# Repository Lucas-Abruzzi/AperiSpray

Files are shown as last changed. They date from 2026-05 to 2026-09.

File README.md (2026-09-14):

# AperiSpray

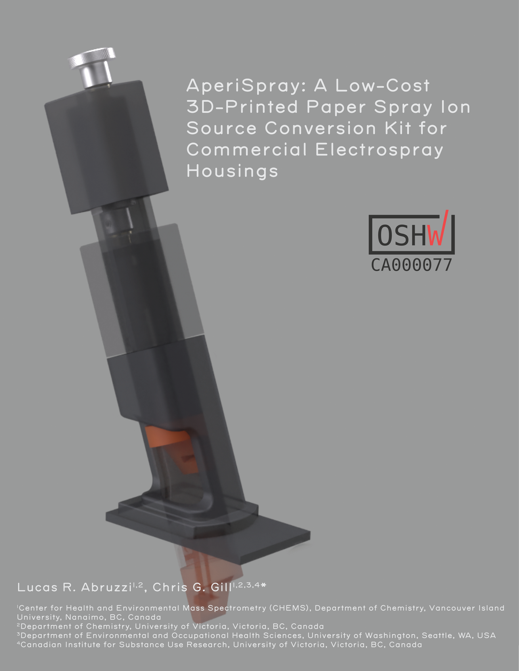
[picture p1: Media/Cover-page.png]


## Table of Contents
- [Overview of Source](https://github.com/Lucas-Abruzzi/AperiSpray/tree/main#overview-of-source)
    - [Disclaimer](https://github.com/Lucas-Abruzzi/AperiSpray/tree/main#disclaimer)
    - [Schematic](https://github.com/Lucas-Abruzzi/AperiSpray/tree/main#schematic)
    - [Parts List](https://github.com/Lucas-Abruzzi/AperiSpray/tree/main#parts-list)
- [Source Construction](https://github.com/Lucas-Abruzzi/AperiSpray/tree/main#source-construction)
    - [3D Printing](https://github.com/Lucas-Abruzzi/AperiSpray/tree/main#printing-parts)
    - [Source Disassembly](https://github.com/Lucas-Abruzzi/AperiSpray/tree/main#source-disassembly)
    - [Soldering the Electronics](https://github.com/Lucas-Abruzzi/AperiSpray/tree/main#soldering-electronics)
    - [Assembling the Shaft Assembly](https://github.com/Lucas-Abruzzi/AperiSpray/tree/main#assembling-the-shaft-assembly)
    - [Assembling the High-Voltage Termination](https://github.com/Lucas-Abruzzi/AperiSpray/tree/main#assembling-the-high-voltage-termination)
    - [Installing the Strip Mount](https://github.com/Lucas-Abruzzi/AperiSpray/tree/main#installing-the-strip-mount)
    - [Installing Assembly in the ESI Housing](https://github.com/Lucas-Abruzzi/AperiSpray/tree/main#installing-assembly-in-the-esi-housing)
- [Opensource Strip Cartridge Construction](https://github.com/Lucas-Abruzzi/AperiSpray/tree/main#opensource-strip-cartridge-construction)
    - [Cutting Paper Strips](https://github.com/Lucas-Abruzzi/AperiSpray/tree/main#cutting-paper-strips)
    - [Printing Strip Holder and Strip Holder Clips](https://github.com/Lucas-Abruzzi/AperiSpray/tree/main#printing-strip-holders-and-strip-holder-clips)
    - [Assembling Strip Cartridges](https://github.com/Lucas-Abruzzi/AperiSpray/tree/main#assembling-strip-cartridges)
- [Operating Instructions](https://github.com/Lucas-Abruzzi/AperiSpray/tree/main#operating-instructions)
    - [Positioning Calibration Procedure](https://github.com/Lucas-Abruzzi/AperiSpray/tree/main#positioning-calibration-procedure)
    - [Spray Solvent Delivery Set Up](https://github.com/Lucas-Abruzzi/AperiSpray/tree/main#spray-solvent-delivery-set-up)
    - [Method Development](https://github.com/Lucas-Abruzzi/AperiSpray/tree/main#method-development)
    - [Sample Preparation](https://github.com/Lucas-Abruzzi/AperiSpray/tree/main#sample-preparation)
    - [Loading and Analyzing a Strip Cartridge](https://github.com/Lucas-Abruzzi/AperiSpray/tree/main#loading-and-analyzing-a-strip-cartridge)
    - [Trouble Shooting](https://github.com/Lucas-Abruzzi/AperiSpray/tree/main#trouble-shooting)
    - [Unloading Used Strip Cartridges](https://github.com/Lucas-Abruzzi/AperiSpray/tree/main#unloading-used-strip-cartridges)

## Overview of Source

The AperiSpray is a low-cost, simple to use assembly that converts existing Thermo Scientific OptaMax NG heated electrospray ionization (H-ESI) housings into paper spray ion sources, making use of 3D-printed parts and off-the-shelf hardware. AperiSpray features instrument-controlled high-voltage and spray solvent delivery and can use either in-house-built or commercially available paper spray strips. Many laboratories that perform routine LC-MS analyses already have surplus H-ESI sources available for conversion, and those that don’t, can purchase inexpensive used or defective housings from third party sellers, making AperiSpray a low-investment option for those wanting to experiment with PS-MS. Additionally, unlike the commercial PS-MS platform, AperiSpray is compatible with almost any Thermo Scientific mass spectrometer with an atmospheric pressure interface, allowing it to be coupled to high-resolution Orbitrap instruments. Although outside the scope of this document, components of this design could be adapted to construct PSI sources for instruments from other manufacturers.

### Disclaimer

Following these instructions may void instrument warranties, risk damage to instruments, and/or expose you to risk of electrical shock. Do so at your own risk. Do not perform modifications to the source while it is mounted to the instrument. Ensure that the instrument is in “standby” or “off” before attempting to load or unload a strip cartridge from the source and never raise the shaft while the spray voltage is turned on.

### Schematic

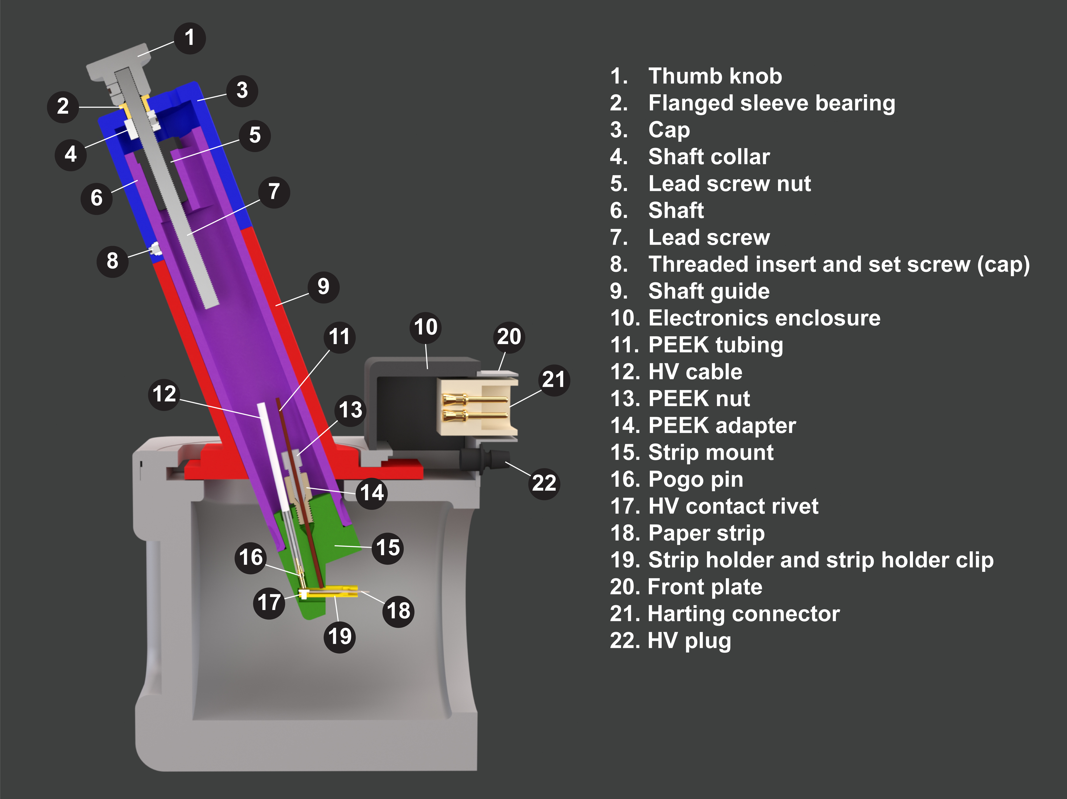
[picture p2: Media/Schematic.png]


### Parts List

| Designator | Qty | Source | Part No. | Cost /ea (CAD) | Material |
| --- | --- | --- | --- | --- | --- |
| Shaft guide  | 1 | 3D-printed | N/A | $2.43 | PLA-CF |
| Shaft  | 1 | 3D-printed | N/A | $2.46 | PLA-CF |
| Cap  | 1 | 3D-printed | N/A | $1.46 | PLA-CF |
| Electronics enclosure | 1 | 3D-printed | N/A | $1.60 | PLA-CF |
| HV female connector | 1 | 3D-printed | N/A | $0.16 | PLA |
| Strip mount | 1 | 3D-printed | N/A | $0.72 | PA6-GF |
| Strip holder + clip  | N/A* | 3D-printed | N/A | $0.06 | PA6-GF |
| Strip tray | 1 | 3D-printed | N/A | $0.73 | PLA |
| Harting connector | 1 | Digikey.ca | [1195-1808-ND](https://www.digikey.ca/en/products/detail/harting/09200102612/3180391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) | $29.82 | PC |
| 2.15 kΩ resistor | 1 | Digikey.ca | [56-SFR2500002151FR500CT-ND](https://www.digikey.ca/en/products/detail/vishay-beyschlag-draloric-bc-components/SFR2500002151FR500/595788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) | $0.20 | Ceramic |
| 22 MΩ resistor | 1 | Digikey.ca | [BC4913CT-ND](https://www.digikey.ca/en/products/detail/vishay-beyschlag-draloric-bc-components/VR37000002205JA100/7350819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) | $0.74 | Ceramic |
| Pogo pin | 1 | Digikey.ca | [54-7949-0-15-20-09-14-11-0-ND](https://www.digikey.ca/en/products/detail/mill-max-manufacturing-corp/7949-0-15-20-09-14-11-0/13531603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) | $4.76 | Brass alloy |
| 20 AWG wire | 4 cm | mcmaster.com | [8054T184](https://www.mcmaster.com/products/8054t184/) | $0.02 | Copper |
| HV cable | 70 cm | mcmaster.com | [8296K17](https://www.mcmaster.com/products/8296k17/) | $25.67 | Silicone |
| 1/4"-PP tubing | 6 cm | mcmaster.com | [5392K12](https://www.mcmaster.com/catalog/132/170/5392K12) | $0.20 | PP |
| Threaded insert | 1 | mcmaster.com | [94100A110](https://www.mcmaster.com/products/94100a110/) | $0.70 | SS |
| Set screw (cap) | 1 | mcmaster.com | [92605A098](https://www.mcmaster.com/products/92605a098/) | $0.15 | SS |
| Thumb knob | 1 | mcmaster.com | [2577K21](https://www.mcmaster.com/products/2577k21/) | $12.57 | SS |
| Flanged sleeve bearing | 1 | mcmaster.com | [7815K11](https://www.mcmaster.com/products/7815k11/) | $5.17 | Bronze |
| Lead screw | 1 | mcmaster.com | [6350K694](https://www.mcmaster.com/products/6350k694/) | $81.44 | SS |
| Shaft collar | 1 | mcmaster.com | [6462K12](https://www.mcmaster.com/products/6462k12/) | $7.17 | SS |
| Lead screw nut | 1 | mcmaster.com | [6350K683](https://www.mcmaster.com/products/6350k683/) | $31.63 | POM |
| Mounting screws | 2 | mcmaster.com | [92196A151](https://www.mcmaster.com/products/92196a151/) | $0.11 | SS |
| Set screw (strip-mount) | 1 | mcmaster.com | [92765A005](https://www.mcmaster.com/products/92765a005/) | $0.33 | Steel alloy |
| HV contact rivets | N/A* | aliexpress.com | [GB109](https://www.aliexpress.com/item/1005007409269038.html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) | $0.03 | Aluminum |
| Chromatography paper | N/A* | Fishersci.ca | [057146](https://www.fishersci.ca/shop/products/whatman-31et-chr-chromatography-paper/057146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) | $0.02 | Cellulose |
| PEEK nut | 1 | Coleparmer.ca | [0201343](https://www.coleparmer.ca/i/idex-fingertight-one-piece-long-thread-natural-peek-1-16-od-tubing-10-32-coned-10-pk/0201343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) | $11.32 | PEEK |
| PEEK nut adapter | 1 | Coleparmer.ca | [0201420](https://www.coleparmer.ca/i/idex-threaded-adapter-peek-0-040-id-10-32-coned-f-to-1-4-28-flat-bottom-m/0201420) | $40.81 | PEEK |
| Crimp butt connector | 1 | grainger.ca | [GGE4FRH9](https://www.grainger.ca/en/product/SPLICE-CONNECTOR-VINYL-RED-PK100/p/GGE4FRH9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) | $0.13 | Vinyl |
| Pen tube | 1 | grainger.ca | [TOYGSM11-2](https://www.grainger.ca/en/product/PEN-BALLPT-MED-BIC-ROUND-BLUE-12-PK/p/TOYGSM11-2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) | $0.47 | PP |
| Heat shrink | 1 | homedepot.ca | [1000843481](https://www.homedepot.ca/product/gardner-bender-3-inch-l-x-assorted-diameter-heat-shrink-black-tubing-set-of-160-/1000843481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) | $25.41 | Polyolefin |

*Denotes consumable

## Source Construction

### Printing Parts

#### Filament
For the cap, shaft, shaft guide, electronics enclosure, and strip tray, most standard FDM filament materials are acceptable. We prefer carbon-fiber PLA because it is dimensionally stable, easy to print and has a desirable surface texture. For the strip mount and strip holders, we recommend a material that is resistant to solvent to prevent interference and instrument contamination. In normal operation of the source, the strip mount should not come in direct contact with spray solvent, so PLA or ABS can be used if necessary, however in our experience, solvent overflow will occasionally occur while calibrating solvent deposition rate and volume, so a solvent-resistant material is highly recommended. Strip holders come in contact with solvent during normal operation. Some good options for strip holders (and strip mounts) include natural polyoxymethylene (POM), and natural PA6 Nylon. We recommend natural glass fiber reinforced PA6 nylon as it is both chemically resistant and easy to print on consumer grade printers, whereas POM suffers from poor print-bed adhesion and severe warping.

#### Printer Settings
Printer settings are highly dependent on the filament material and printer. We recommend using your printer’s default print settings for the filament chosen and adjusting as necessary.

#### Slicer Settings

<ins>Shaft guide:</ins>

Print the shaft guide in an upright position. Tree support is recommended for the overhang in the loading cutaway.

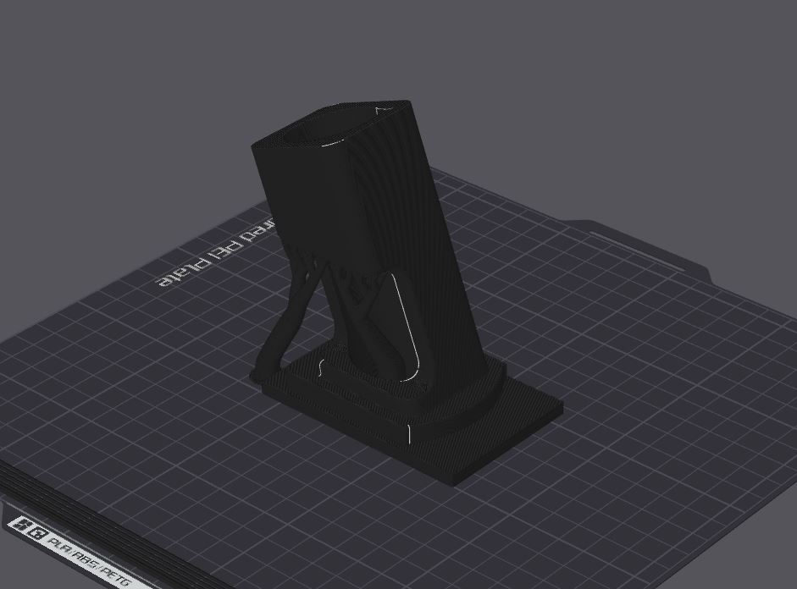
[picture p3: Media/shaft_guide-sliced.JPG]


<ins>Shaft:</ins>

We recommend printing the shaft upright to ensure the surface that mates with the lead screw nut is flat. You will need support under the mounting bracket on the inside of the shaft. 

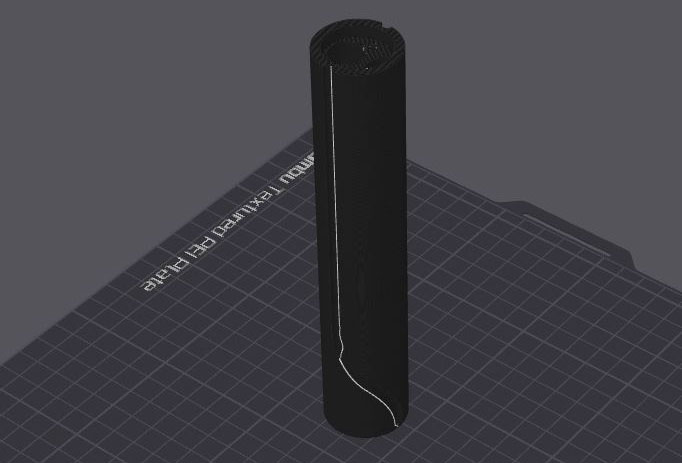
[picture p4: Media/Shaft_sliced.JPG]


<ins>Cap:</ins>

The cap should be printed upside down with the top face against the build plate. No support is necessary. We recommend using a contrasting filament for the warning text and HV symbol if multi-filament printing is available. 

<ins>Electronics enclosure:</ins>

Print the electronics enclosure with the backside down on the build plate. Support is only needed for the bottom lips.

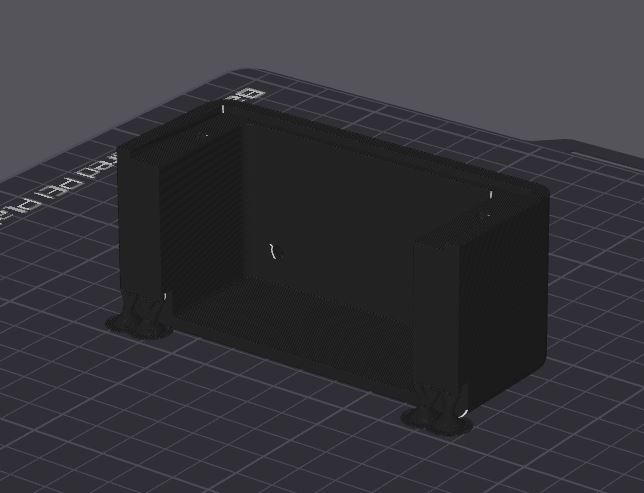
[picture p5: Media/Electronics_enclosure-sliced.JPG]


<ins>HV female connector:</ins>

Print with the threaded end up. No support is needed.

<ins>Strip mount (for open-source or commercial strips):</ins>

The strip mount is best printed upside down with support under the ridge, in the strip pocket, and in the threaded solvent hole.

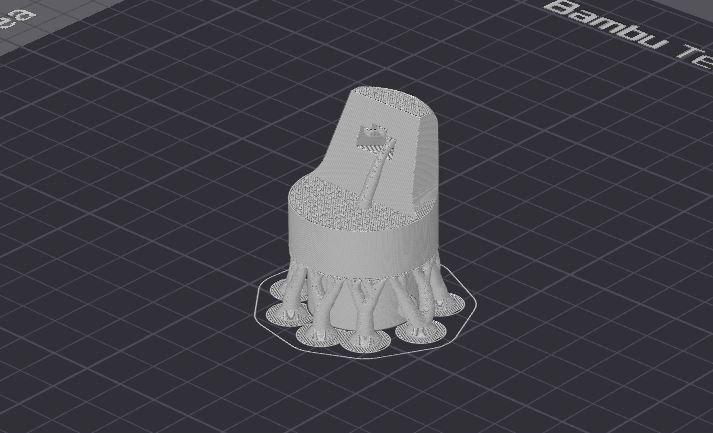
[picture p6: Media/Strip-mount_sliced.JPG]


<ins>Calibration Strips:</ins>

Calibration strips are for calibrating the paper strip position relative to the inlet of the mass spectrometer. They are inserted into the strip pocket on the strip mount and extend to where the opening of the inlet should be relative to the strip mount. By default, the calibration strips extend 4 mm further from the strip mount than actual paper strips would to create a 4 mm gap between paper strips and the inlet when used to calibrate positioning. If a larger or smaller gap is desired, the FreeCAD file for the calibration strips can be modified by increasing or decreasing the “Inlet_gap” variable in the variable set. Print calibration strips out of whatever filament you have on hand. They are best printed in an upright position with the backside against the print bed. Support is only necessary on the calibration strip for the commercial strip mount.

### Source Disassembly

Remove the 4 screws holding the front plate on the source and pull the front plate away from the housing.



Remove the metal cover protecting the electronic and pneumatic connections.

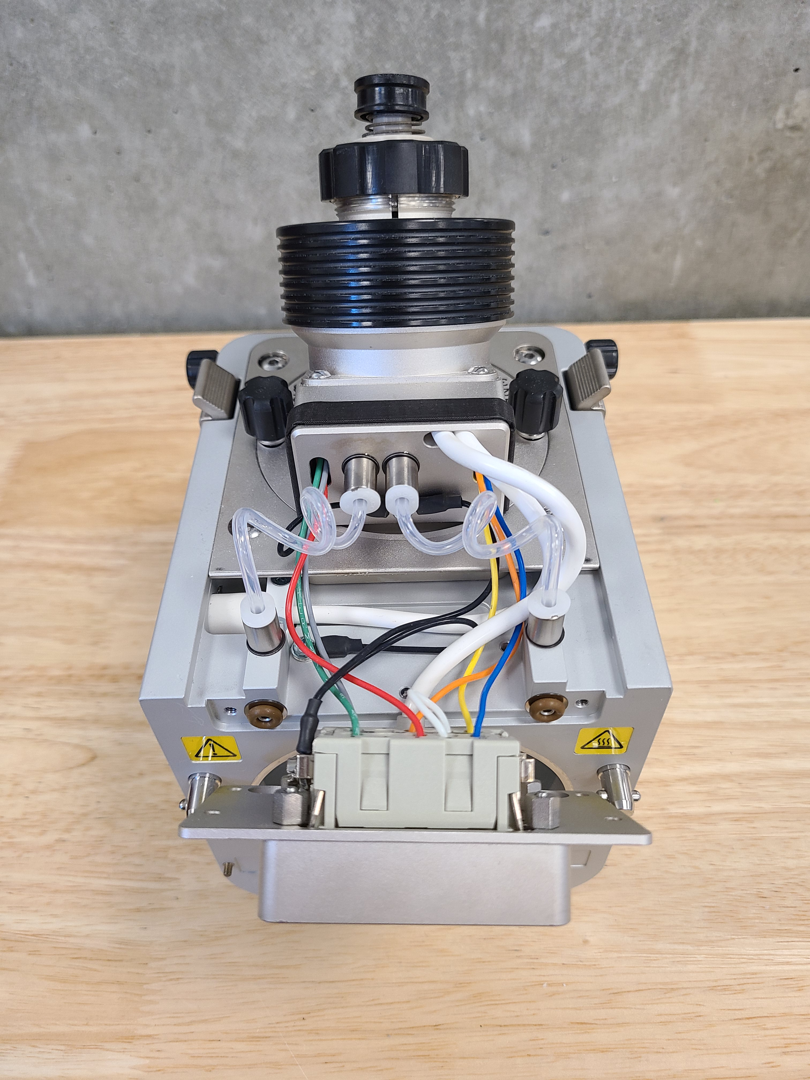
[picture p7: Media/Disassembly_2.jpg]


Disconnect gas lines by pushing down on quick connect tab while pulling up on gas tubing. Remove the retainer knobs for the API spray insert and heater assembly and the 4 socket head screws that mount the spray insert and heater assembly to the housing. 

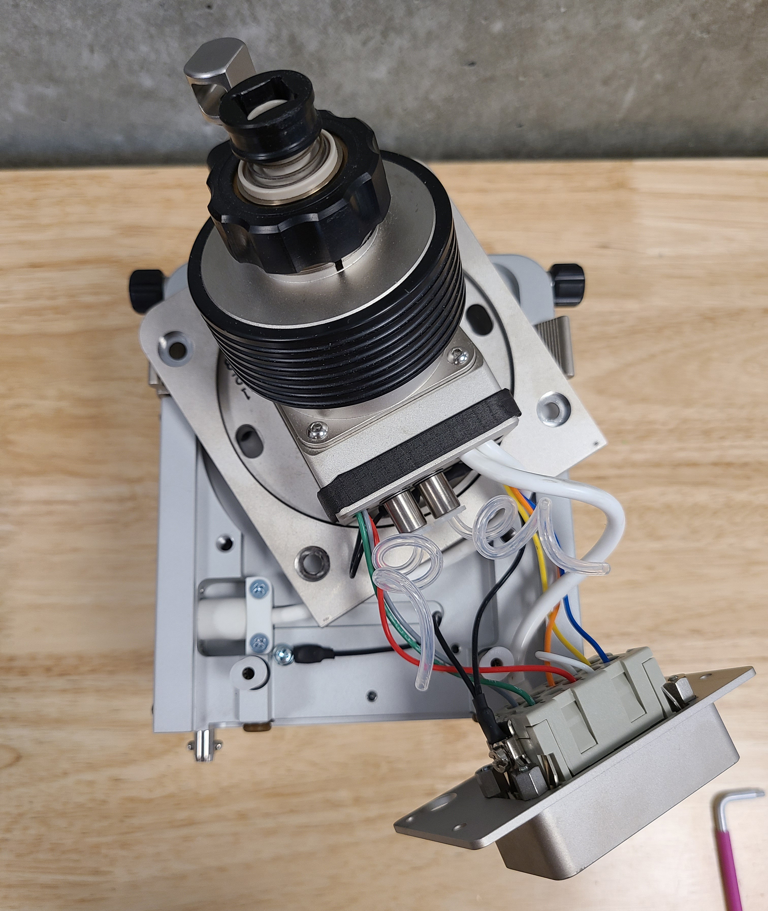
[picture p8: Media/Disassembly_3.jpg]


Remove the 3 socket head screws and the side panel on the right side of the housing. 



Remove the 4 socket head screws and metal plate covering the APCI corona discharge needle high-voltage connection.



Remove the 2 screws and the plastic mount housing the high-voltage corona discharge needle connector and adjacent grounding connection. The right-side panel can be replaced.



Remove the API spray insert and the 4 socket head screws and the heater assembly cover.

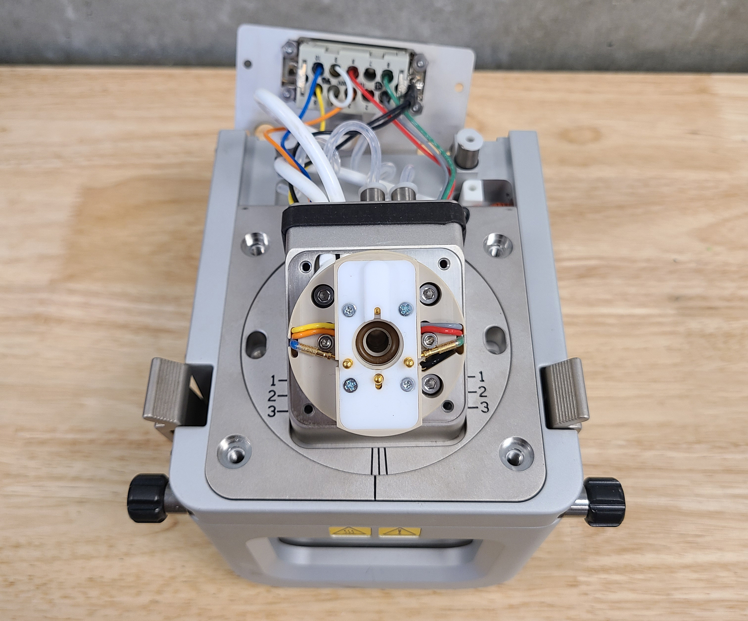
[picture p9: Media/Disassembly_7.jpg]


Remove 3 socket head screws holding on the heater assembly and carefully pull the heater assembly away from the mounting body while feeding wire.

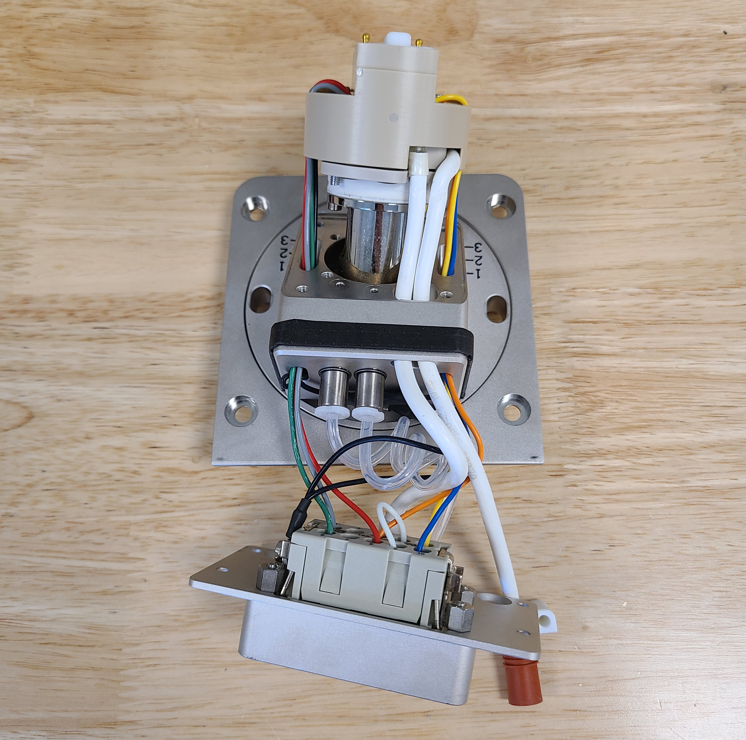
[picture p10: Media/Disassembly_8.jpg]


Carefully slide the positioning plates up and over the heater assembly and electrical connections to separate them from the electronic components

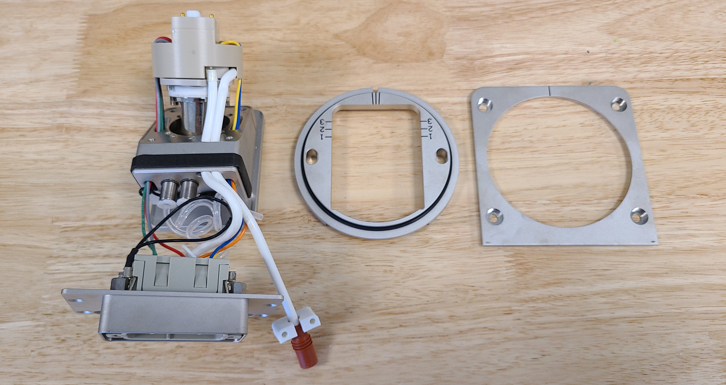
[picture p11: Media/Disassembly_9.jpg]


Loosen and remove the 4 nuts retaining the 10-pin Harting connector to the front plate and unscrew the transparent square nut connecting the HV wire to the HV plug on the front plate.

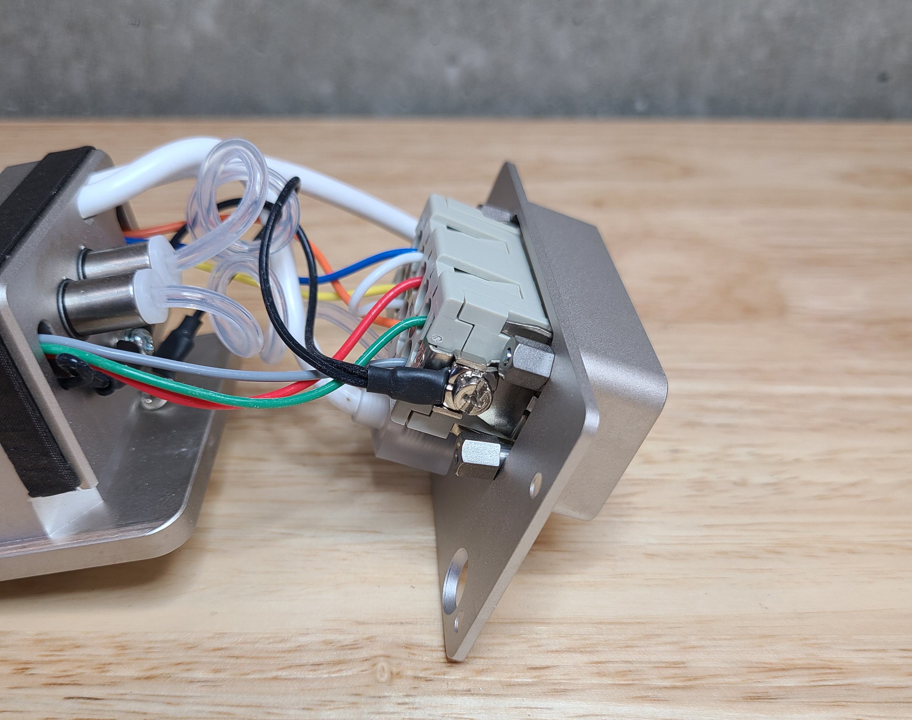
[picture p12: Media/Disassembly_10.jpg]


Separate the connector from the front plate.

### Soldering the Electronics

Add the nuts from the original Harting connector to the new one and mount the new connector to the front plate. Thread a 3/8-32 panel nut onto the HV plug to clamp it to the front plate and tighten it to prevent the HV plug from turning freely in the front plate. 

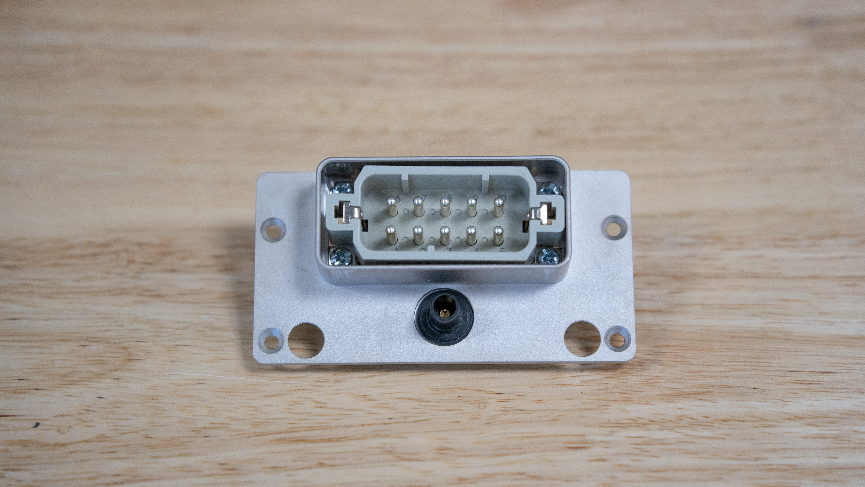
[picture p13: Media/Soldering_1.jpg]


Cut a 10 cm section of HV wire and strip 1 cm from each end. Cut a second 60 cm section and strip 1 cm from one end. Solder the 22 MOhm resistor between the two sections of HV wire. Cut a 6 cm section of 1/4”- polypropylene tubing and slide it over the resistor. 

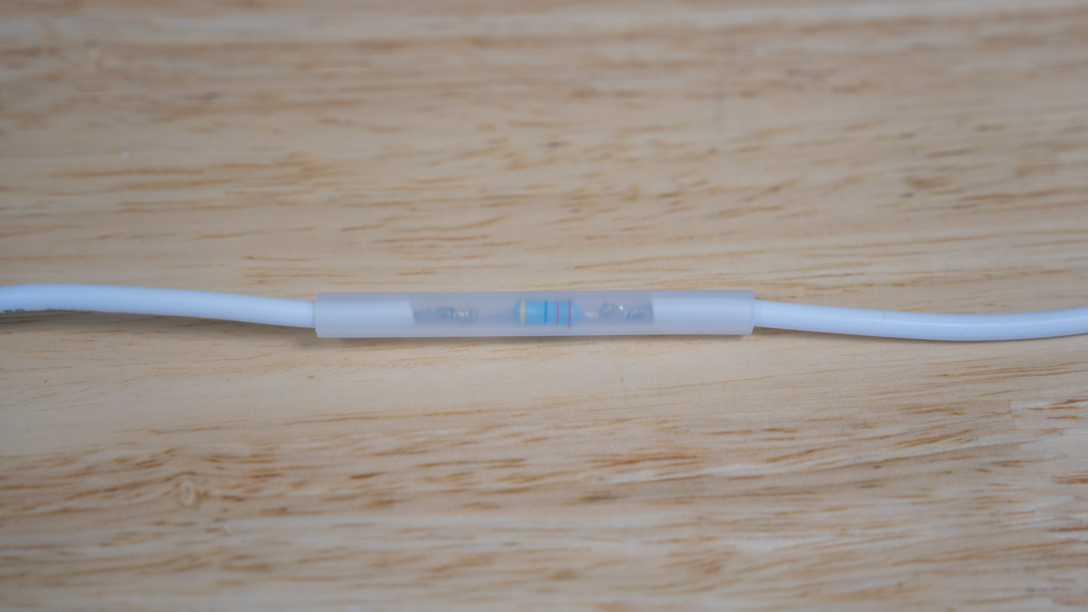
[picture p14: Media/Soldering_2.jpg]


Add heat shrink over the tubing. Add a short section of heat shrink to each end of the previous heat shrink to prevent the tube from sliding. Feed the long end of the HV cable through the port in the top of the 3D-printed electronics enclosure and carefully fold the resistor in.

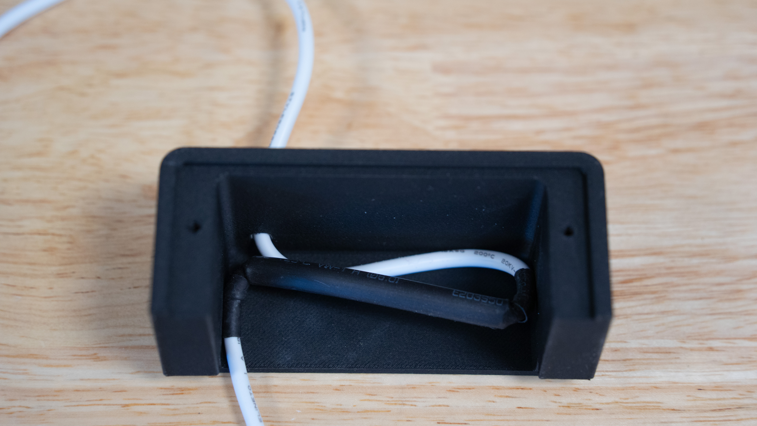
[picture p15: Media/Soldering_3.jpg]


Cut the plastic insulation off one end of a butt splice crimp connector using wire cutters.



Slide the 3D-printed HV connector onto the short end of the HV wire with the threaded end facing out. Feed the short end of the HV wire into the uncut end of the crimp connector and crimp. Slide the cut end of the crimp connector over the gold-plated solder well on the inside end of the HV plug mounted to the front plate. It should slide on easily but make firm contact.

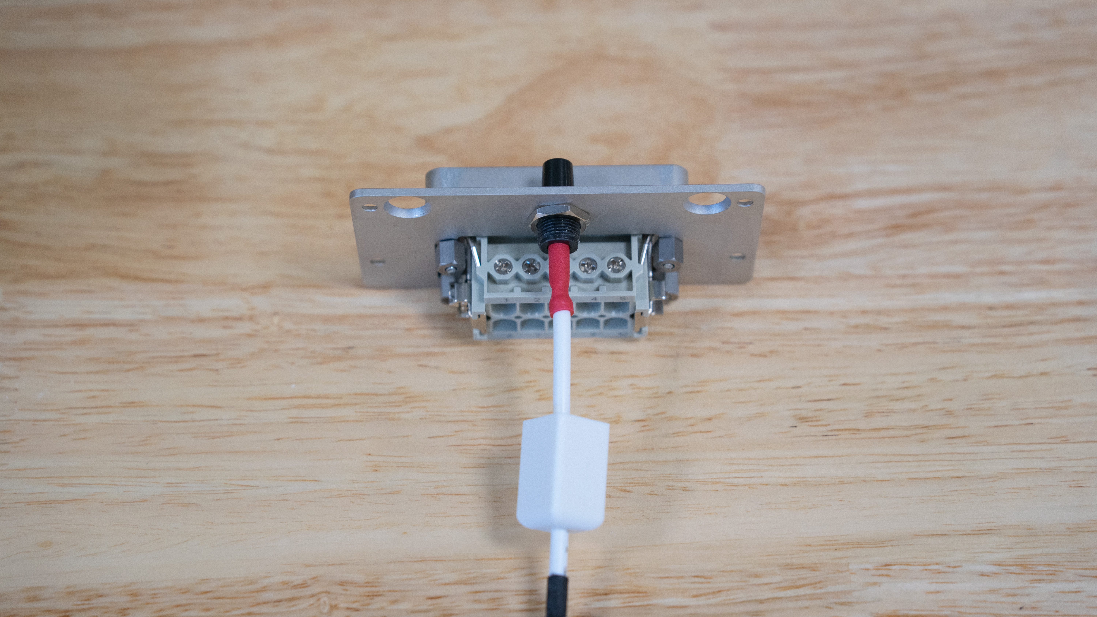
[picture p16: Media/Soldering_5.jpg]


Heat shrink a 2.15 kOhm resistor, leaving the last 5 mm of each lead exposed. Strip 5 mm from each end of a 4 cm section of wire to make a jumper. Place the resistor between pins 6 and 10 in the Harting connector and place the wire jumper between pins 4 and 9. Tighten the set screws fix the connections.

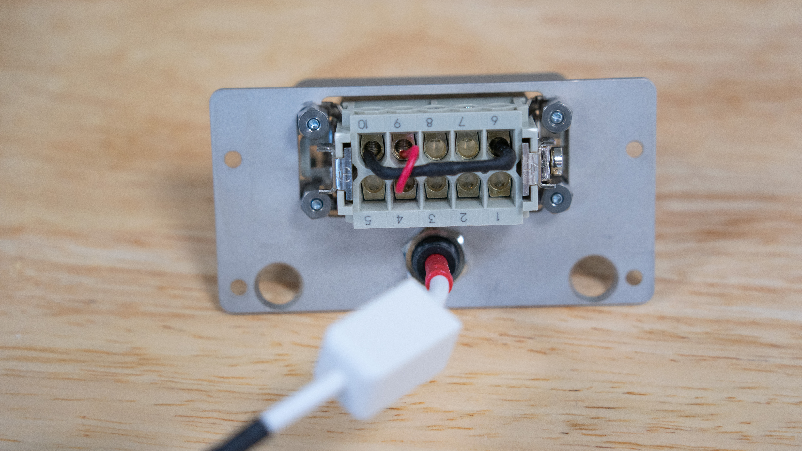
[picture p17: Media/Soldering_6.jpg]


Thread the 3D-printed HV female connector onto the inside end of the HV plug and tighten to secure the crimped HV line to the HV plug. Carefully fold the HV cable into the 3D-printed electronics enclosure and mount the front plate to the electronics enclosure using the 2 of the original flush head mounting screws.

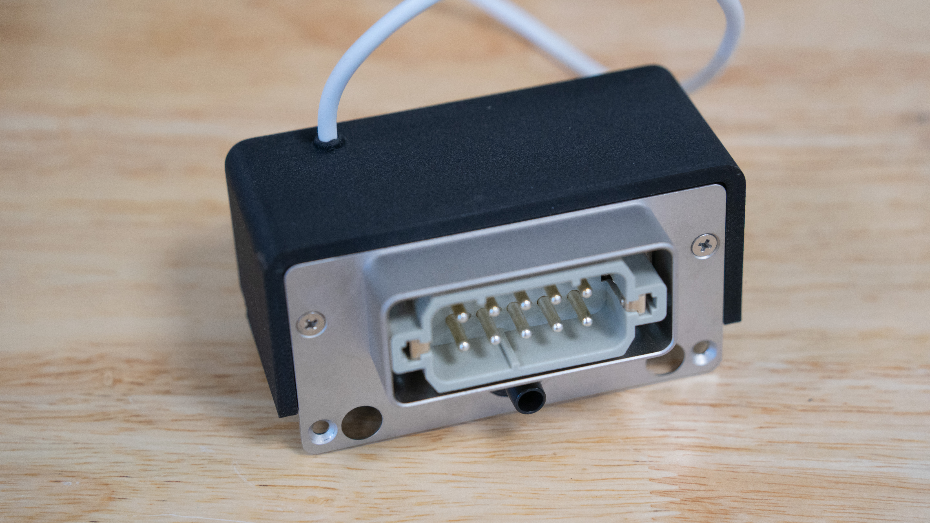
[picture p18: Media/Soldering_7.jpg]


### Assembling the Shaft Assembly

Cut the 1/4-40 lead screw to a length of approximately 9 cm using whatever cutting tool you have on hand. The threads on the cut end do not need to be preserved. Modify the lead screw nut so it fits into the shaft with the two mounting holes lining up with the corresponding threaded holes on the shaft. The nut is made of acetal/POM, so it is easily shaped with common tools (files, hacksaw, dremel, etc.)



Thread the uncut end of the lead screw into the lead screw nut from the bottom until approximately 29 mm protrudes from the top of the nut. Mount the lead screw nut in the 3D-printed shaft using two 6-32 screws.



Slide the shaft up through bottom of shaft guide by lining up the grooves in the shaft with the guide pins on the inside of the guide shaft. All 3D printers print slightly differently, so tolerances may need to be adjusted in the original design files. Variable sets have been included in each design file to simplify adjustments of critical dimensions. If the shaft does not slide smoothly in the shaft guide, you may need to increase the bore diameter of the shaft guide by editing the “Bore_diameter” variable in the FreeCAD [file](https://github.com/Lucas-Abruzzi/AperiSpray/blob/main/FreeCAD/Shaft_guide.FCStd) for the shaft guide. If the shaft is too loose in the shaft guide, decrease the bore diameter. If the shaft slides smoothly in the shaft guide but cannot pass the guide pins, you may need to increase the pin-to-pin distance (“Pin_to_pin_distance” variable in the FreeCAD file for the shaft guide) or decrease the pin radius (“Pin_radius” variable). If the shaft has rotational play, you may have to decrease the pin-to-pin distance or increase the pin radius.



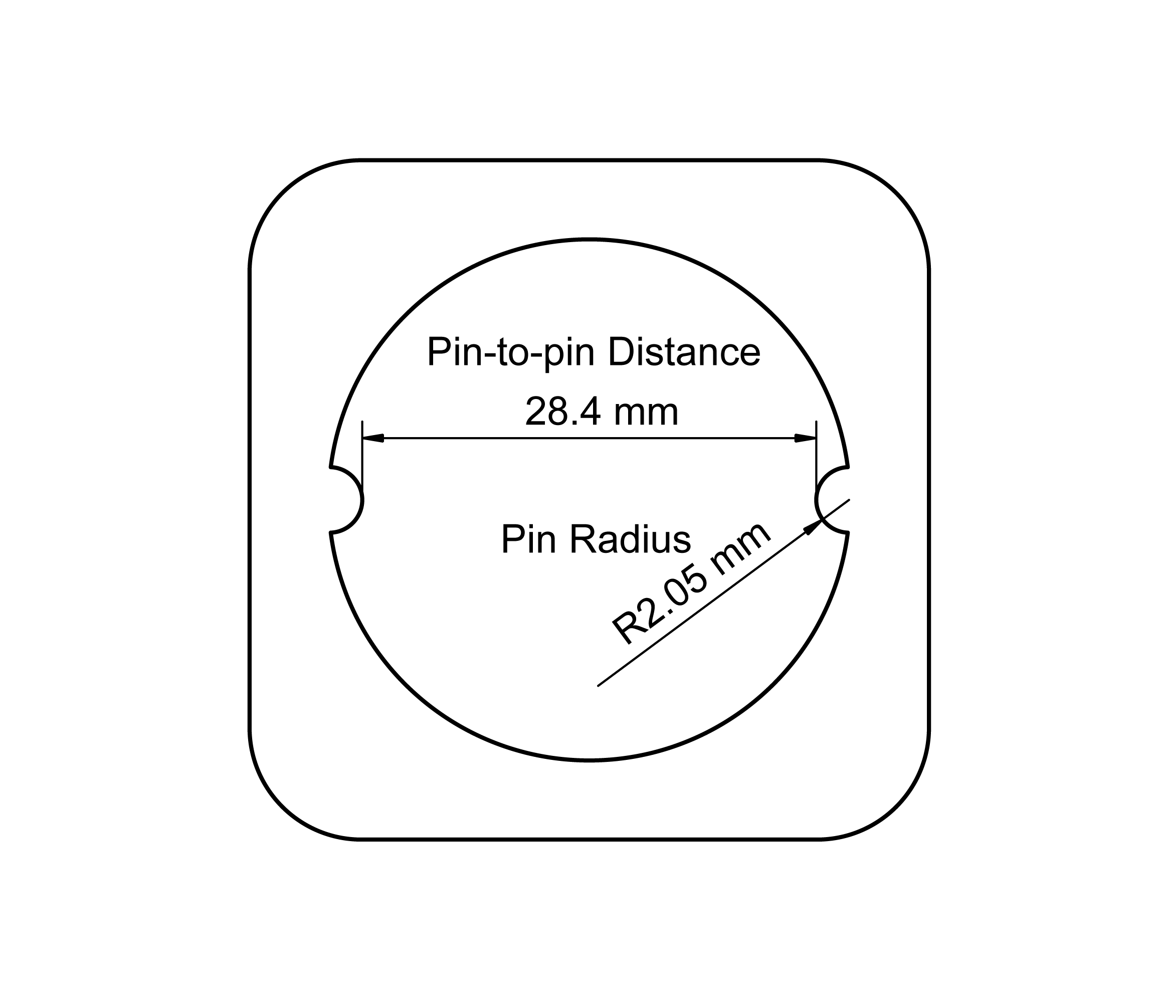
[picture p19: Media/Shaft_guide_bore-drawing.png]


Push brass flanged sleeve bearing into the hole in the 3D-printed cap and press the M3 threaded insert into the side mounting hole from the inside.



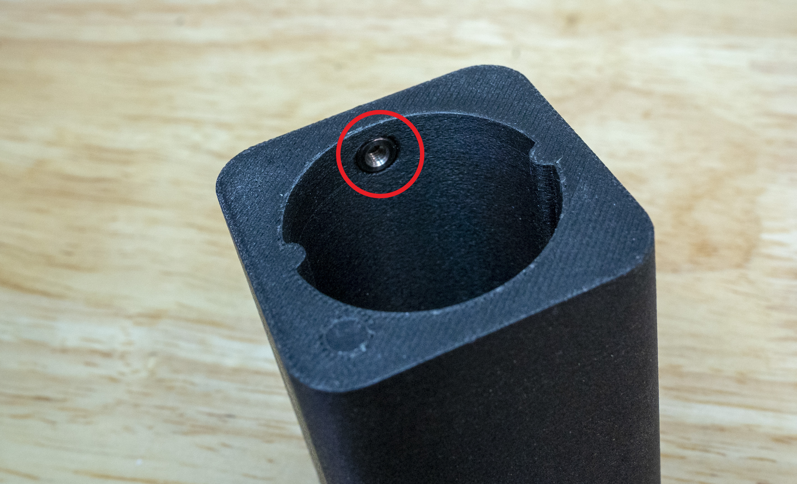
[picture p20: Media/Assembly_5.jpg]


Slide shaft collar over the top end of the lead screw and tighten the set screw 13 mm below the top.



Guide lead screw up though the brass bushing in the cap. Slide the thumb knob onto the lead screw. While pushing the thumb knob against the shaft collar, tighten the set screw on the thumb knob to fix it to the lead screw. Turn the thumb knob clockwise while lining up the grooves on the shaft with the ridges on the inside of the cap until the cap slides over the shaft.

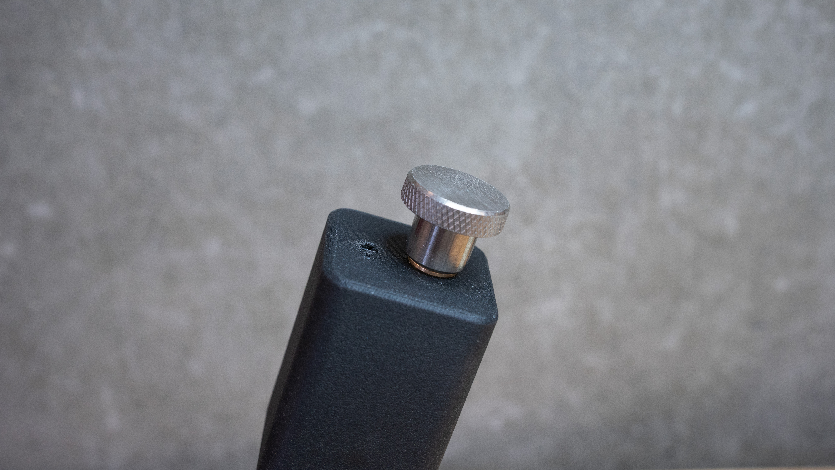
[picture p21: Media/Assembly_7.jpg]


Thread M3 set screw into threaded insert on back side of cap, but don’t tighten it all the way. Feed the free end of the HV wire coming from the electrical enclosure through the hole in the top of the cap and down through the shaft. Do the same with one end of the PEEK line.

### Assembling the High-Voltage Termination

Disassemble a Bic Round Stic® pen and flush the polypropylene ink cartridge tube out with methanol to remove all the ink. Cut a 60 mm section of the pen tubing. Strip 70 mm of insulation off terminus of HV wire. Slide a 60 mm section of heat shrink onto the stripped portion of the wire and heat.



Slide the plastic pen tube over the heat-shrinked portion of the wire all the way to the terminus of the insulation and solder the HV pogo pin onto the terminus of the wire.

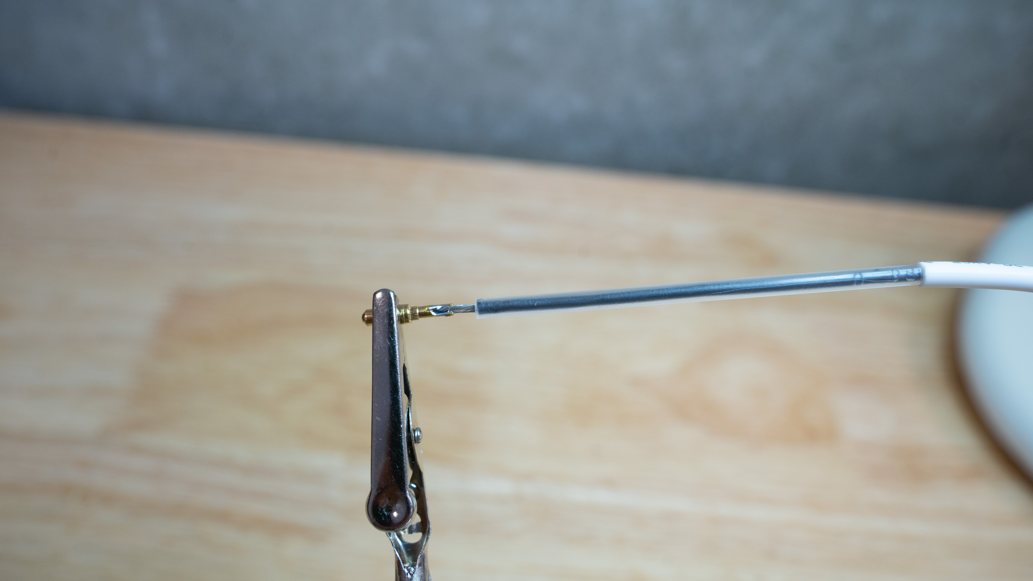
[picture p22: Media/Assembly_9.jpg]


Slide the plastic tube down onto the splines of the pogo pin and heat shrink where the plastic tube meets the HV wire insulation.

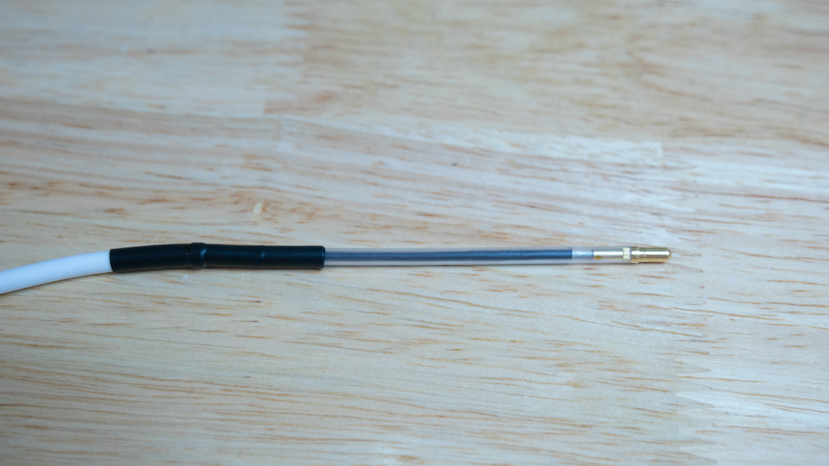
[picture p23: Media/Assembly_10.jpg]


### Installing the Strip Mount

(procedure is the same whether using the commercial strip cartridges or strip cartridges produced in-house).

Feed PEEK tubing and the HV terminus through the holes on the top surface of the cap and down through the shaft.



Slide a 10-32 threaded (male) 1/16-inch nut onto the end of the PEEK line. Slide a 10-32 to 1/4-28 adapter onto peak line and begin to thread the 1/16-inch nut into the adapter. Position the bottom of adapter 32 mm from terminus of PEEK line and tighten connection to clamp the PEEK fittings in place on the PEEK tubing.

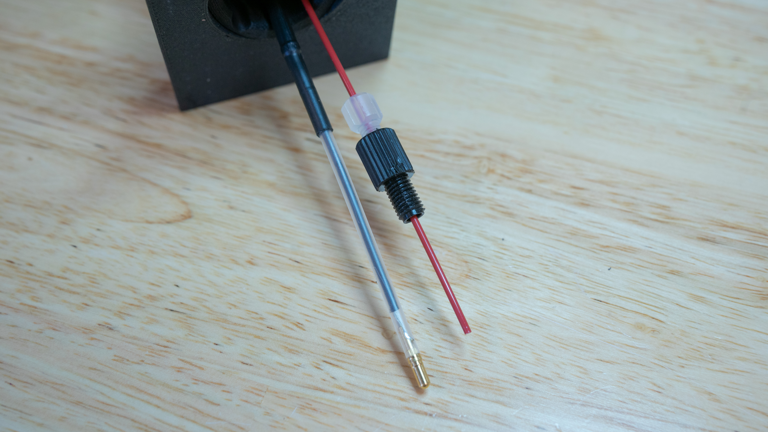
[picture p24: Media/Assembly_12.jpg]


Feed the PEEK terminus into the threaded hole in the 3D-printed strip mount, and the HV terminus into the unthreaded hole. Thread in the 1/4-28 PEEK adapter while ensuring the PEEK tubing is rotating freely within the shaft assembly. Thread the 4-40 set screw into the threaded hole on the side of the strip mount but don’t fully tighten.



Insert a paper strip holder into the strip mount and ensure it is fully seated. If the paper strip holder does not slide in easily, you will need to increase the vertical tolerance by decreasing the “Strip_Height” variable in the FreeCAD [file](https://github.com/Lucas-Abruzzi/AperiSpray/blob/main/FreeCAD/Opensource_strip-holder.FCStd) for the strip holder (if using opensource strip cartridges), or by increasing the “Strip_pocket_height” variable in the FreeCAD [file](https://github.com/Lucas-Abruzzi/AperiSpray/blob/main/FreeCAD/Commercial_strip-mount.FCStd) for the strip mount (if using commercial strip cartridges). If the paper strip holder is loose in the strip mount, you will need to decrease tolerances. Slide the high voltage terminus into the strip mount until it contacts the rivet on the strip cartridge (look down along top of paper strip to ensure). Push it an additional mm to ensure good contact between pogo pin and rivet, but not so far that the pogo pin is fully depressed. Tighten set screw on the side of the strip mount to fix the height of the high voltage contact.



Turn the PEEK adapter nut clockwise until the PEEK terminus is roughly 1 mm above the surface of the paper strip (make sure the PEEK is turning freely within the shaft assembly so as not to introduce torsion in the PEEK tubing). The following image shows a strip mount with properly adjusted high voltage contact and solvent line.

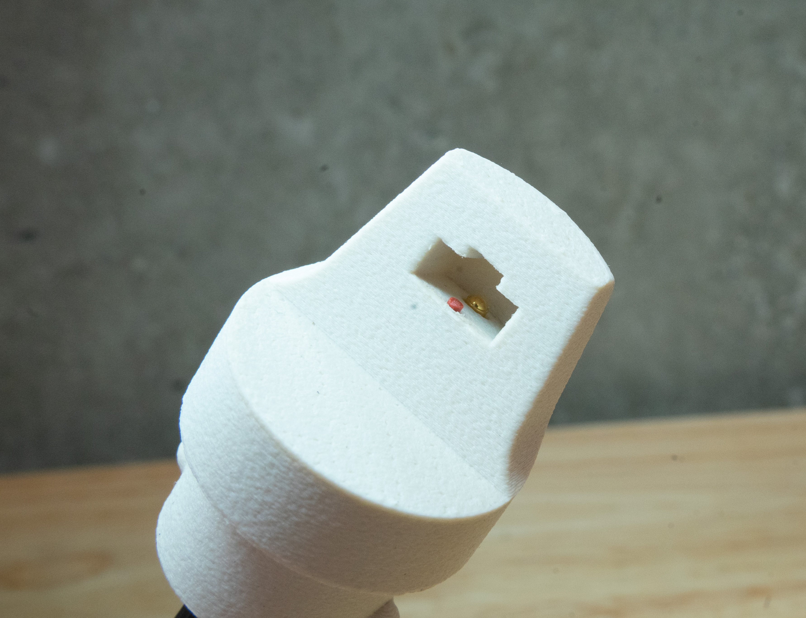
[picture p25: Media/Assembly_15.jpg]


Line up locking lugs on insert with slots on the shaft, slide insert into shaft while twisting clockwise until insert clicks into place. Pull extra slack in high voltage line up through the cap.



### Installing Assembly in the ESI Housing

Pass the electrical enclosure assembly and PEEK tubing up through the bottom of the positioning plates.



Slide the positioning plates over the shaft assembly and seat them on the shaft guide.



Mount the positioning plates and shaft assembly to the ESI housing and replace the 4 mounting screws. Replace the left thumbscrew only, to allow easier access to the loading port in the shaft guide when loading and unloading strip cartridges.

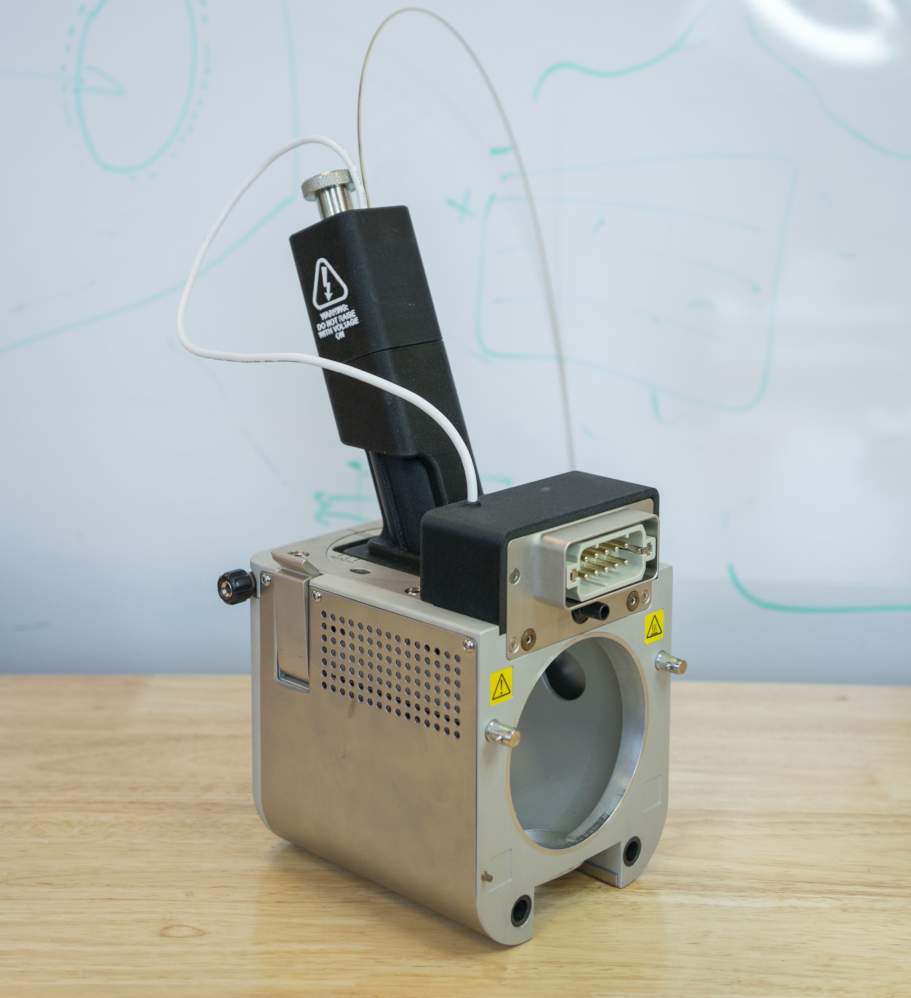
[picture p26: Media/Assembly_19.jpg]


## Opensource Strip Cartridge Construction

### Cutting Paper Strips

If you choose to make your own paper strips, you will need to have a method of cutting the strips out of the chromatography paper. Paper strips can be cut by hand using a razor blade, by custom die cutters, or by a laser cutter. Whichever technique is chosen, it is crucial that the tip of the paper is cut to a fine point without any fraying otherwise you may experience unstable spray. If using a laser cutter, we recommend rinsing the strips in deionized water prior to use to remove pyrolysis products generated from the heat of the laser. We have included an [.svg](https://github.com/Lucas-Abruzzi/AperiSpray/blob/main/SVG/Paper_strip.svg) file for laser cutting. Laser settings must be optimized for your specific laser cutter.

### Printing Strip Holders and Strip Holder Clips

The FreeCAD [file](https://github.com/Lucas-Abruzzi/AperiSpray/blob/main/FreeCAD/Opensource_strip-holder.FCStd) for the strip holder contains the strip holder clip as well. Print the strip holders and the strip holder clips standing vertically with the back surfaces on the build plate. Support should not be necessary, as the overhangs are minimal. 

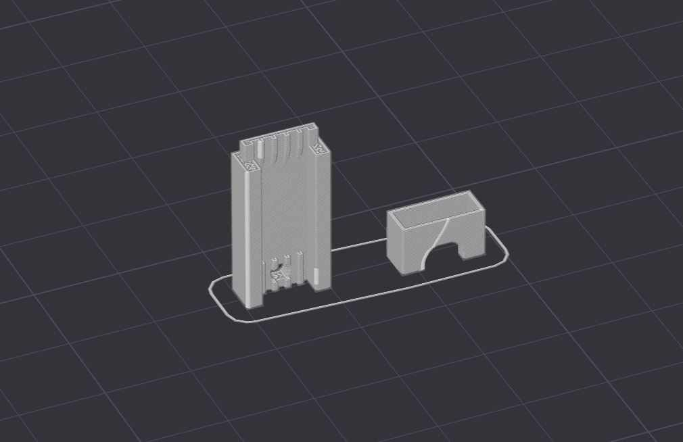
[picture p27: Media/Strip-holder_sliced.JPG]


Print the strip tray laying flat. Support is recommended for the overhangs.

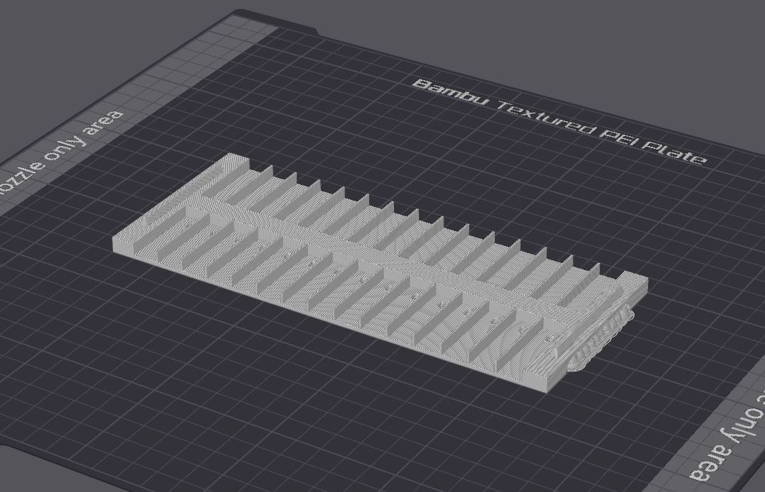
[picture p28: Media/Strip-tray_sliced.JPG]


### Assembling Strip Cartridges

Place a paper strip in a 3D-printed strip holder with the holes in the paper strip and strip holder aligned.

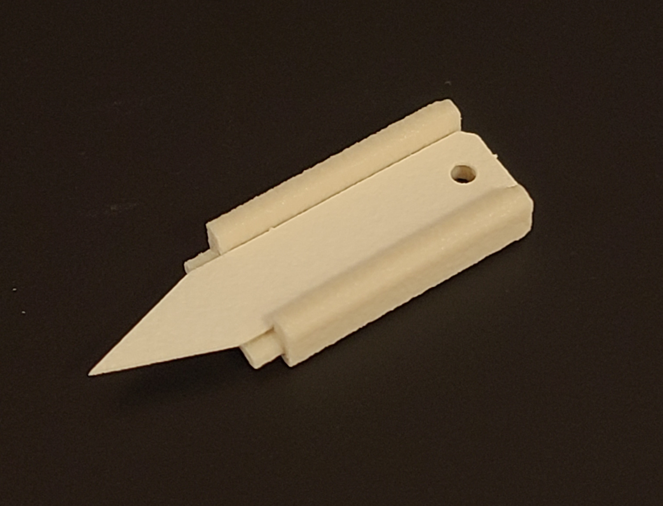
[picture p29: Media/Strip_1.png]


Insert an M2 rivet into the hole in the paper strip and press down until the paper strip is clamped flat against the strip holder.

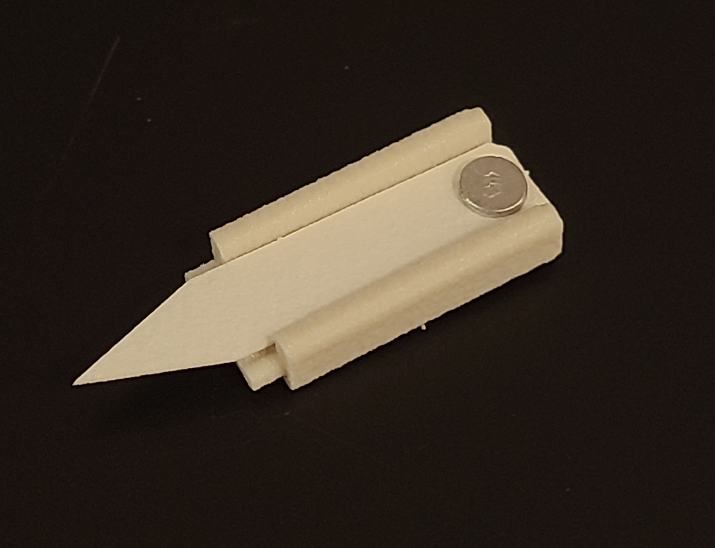
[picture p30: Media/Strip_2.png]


Slide a 3D-printed strip holder clip over the end of the paper strip and onto the strip holder until it clicks. Be careful not to damage the tip of the paper. The paper should be laying flat in the strip holder. You may need to modify tolerances in the FreeCAD [file](https://github.com/Lucas-Abruzzi/AperiSpray/blob/main/FreeCAD/Opensource_strip-holder.FCStd) for the strip holder clip and/or strip holder to ensure a snug fit.

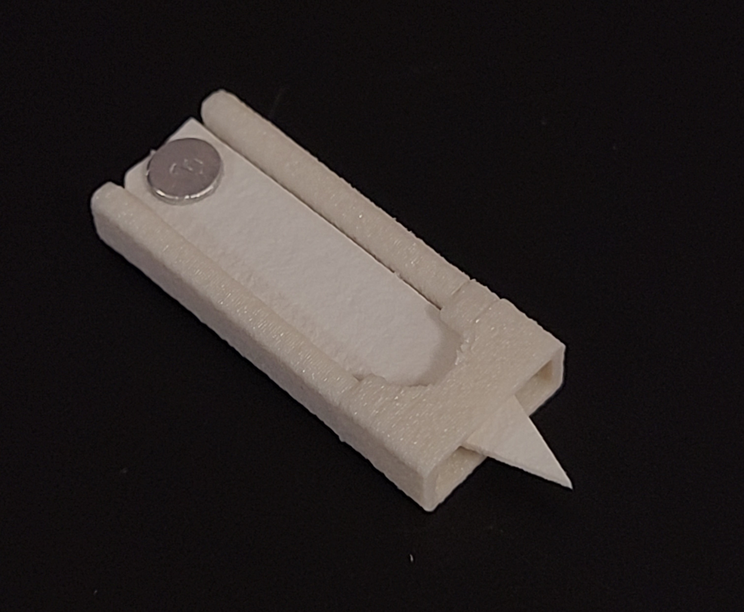
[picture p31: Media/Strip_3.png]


Put each assembled strip cartridge into a 3D-printed strip tray for storage until use. 

## Operating Instructions

The following instructions assume familiarity with instrument software and general instrument use. Refer to your instrument user manual for more specific instructions.

### Positioning Calibration Procedure

-	Turn off the heat to the ion transfer tube / inlet and allow it to fully cool.
-	Loosen the 3 socket head screws and remove the left side panel from the source. Using your fingers, push the view port plug out of the source housing from the inside. 
<p align="center">
    
</p>

-	With source removed from the instrument and the shaft at the bottom of its travel, insert a distance calibration strip and slide the shaft assembly to the back of its travel.
-	Mount the source to the instrument. 
-	While looking through the side view port, slide the shaft assembly forward until the calibration strip is close to the inlet. Adjust the vertical positioning of the calibration strip by turning the thumb knob on the shaft assembly until the center of the calibration strip is aligned with the inlet. When the desired height is reached, tighten the set screw on the backside of the cap.
<p align="center">
    
</p>

-   To calibrate the gap between the inlet and paper strips, slide the shaft assembly forward until the calibration strip touches the inlet. It is crucial that the inlet is cool for this step, or the calibration strip may melt onto the ion transfer tube and contaminate the instrument. Tighten the black retainer knob on the source housing to clamp the shaft assembly in position.
-	Remove the source from the instrument and remove the calibration strip from the strip mount. The viewport plug and side panel can be replaced.

### Spray Solvent Delivery Set Up

The free end of the PEEK tubing can be terminated with a Luer-Lok adapter and connected to a 10 mL glass syringe filled with the desired spray solvent. We recommend priming the solvent delivery line before mounting the first strip cartridge to be run to remove air from the solvent line. 
Using a syringe pump connected to the instrument allows solvent delivery to be programmed into the instrument method along with voltage and scan parameters.

### Method Development

The source should be recognized by the instrument as an ESI source. Develop the instrument method as a direct infusion ESI method. If the source is not recognized, check the resistance across pins 6 and 10 on the Harting connector. You may need to replace the resistor if resistance is greater or less than 2.15 kΩ.

Spray solvent should be selected based on the matrix that your sample is in and the analytes of interest. Refer to the literature for examples of spray solvent composition for different applications.

Program solvent delivery to start at the beginning of the method before voltage turns on to give the analytes time to dissolve into the solvent and the solvent time to wick to the tip of the paper. It takes approximately 120 µL of spray solvent to wet a paper strip, so the solvent flow rate will determine the amount of time needed to pre-wet the paper. Exact solvent flow rates and deposition volumes can be altered to optimize sensitivity and achieve stable spray for the desired method duration. The amount of solvent on the paper can affect the spray mode, which in turn affects ionization and transmission efficiency. A good starting point is a flow rate of 300 µl/min for 0.4 minutes.

Program the voltage to come on once the paper strip is wet. We recommend optimizing spray voltage for the spray solvent, sample matrix, and analytes you are interested in, but 3600 – 4000 V are typical for paper spray methods in positive mode. Negative-mode paper spray requires lower spray voltages to prevent corona discharge and charring of the paper. The duration of high voltage depends on the desired length of the method. Paper spray methods can range from a few seconds to several minutes.

Program data acquisition to continue for several seconds after the voltage turns off so the signal returns to baseline at the end of the method. This will simplify peak integration during data processing.

### Sample Preparation

A diverse variety of sample types are amenable to paper spray mass spectrometry including but not limited to biofluids, water samples, health supplements, pharmaceuticals, forensic residues, and tissue homogenates. In most cases, little to no sample preparation is required and samples can be directly deposited on the paper strips without prior filtration or extraction steps. A sample deposition volume of 10 µL is standard, but lower volumes are sometimes used for complex sample matrices. 

Samples should be allowed to dry on the paper, either at ambient conditions or with the help of a drying oven or desiccator prior to analysis. 

### Loading and Analyzing a Strip Cartridge

To load a strip cartridge, raise the shaft to its upward position by pulling upwards on the cap. The shaft and cap rotate 90° clockwise in the shaft guide to allow strip cartridges to be loaded from the cutout in the right side of the shaft guide.



Ensure the strip cartridge is properly seated in the strip mount and slide the shaft to the bottom of its travel. The bottom of the cap should be flush with the top of the shaft guide.

The strip cartridge is now loaded, and you can run the instrument method. You should get a sharp increase in signal when the voltage turns on and a sharp decrease in signal when the voltage turns off.

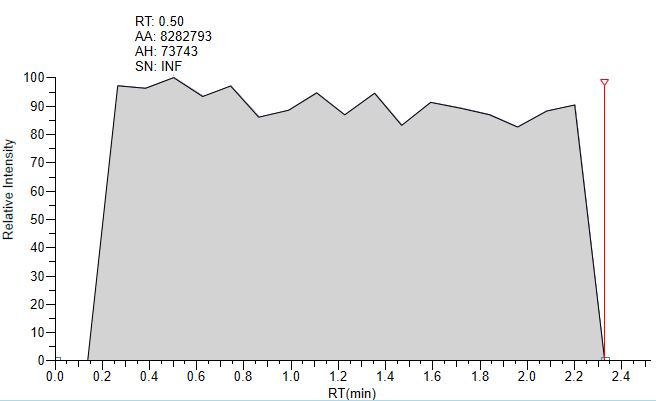
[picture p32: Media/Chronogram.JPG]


### Trouble Shooting

A common issue is solvent overflow caused by excess solvent deposition. This will be noticeable when changing strip cartridges as the sides and bottom of the strip holder will be wet with solvent. When this occurs, reduce either the solvent flow rate or the duration of deposition.

If the signal doesn’t come on, there is either a problem with the instrument method, the electrical contact, the solvent delivery, or the positioning of the paper strip relative to the inlet. Try the following steps in order:

With the voltage turned off, raise the shaft to the upward position and visually inspect the paper strip for solvent. It should be saturated with solvent but not overflowing or forming a drop at the tip. If there is no solvent, prime your syringe pump to remove air and check your instrument method to confirm it is programmed correctly to deliver solvent. You may need to increase the solvent delivery rate / duration.

If solvent is flowing but the paper is not getting wet, solvent may be wicking up the outside of the PEEK tubing into the strip mount. To resolve this, increase the inner diameter of the PEEK tubing.

If the paper looks saturated with solvent and there is still no signal, try moving the shaft assembly forward to decrease the inlet gap.

If there is still no signal, remove the source from the instrument and use a multimeter to confirm continuity between the pogo pin and the HV plug. There should be approximately 22 MΩ of resistance. If there is no continuity, remove the electronics enclosure and determine where the connection is broken.

If the HV line has appropriate resistance, check your instrument method to confirm the voltage and scan parameters are correctly programmed.

If the signal onset is delayed or choppy, try increasing the voltage onset delay or move the shaft assembly forward or back.

### Unloading Used Strip Cartridges

To unload a strip cartridge after data has been acquired and the high voltage is turned off, raise the shaft to the upward position and use gloved fingers or forceps to extract the used strip cartridge. If there is solvent in the strip well on the strip mount, lower the solvent deposition volume for subsequent runs to prevent carryover. The high-voltage contact rivets can be washed and re-used, but the rest of the strip cartridge should be properly disposed of.

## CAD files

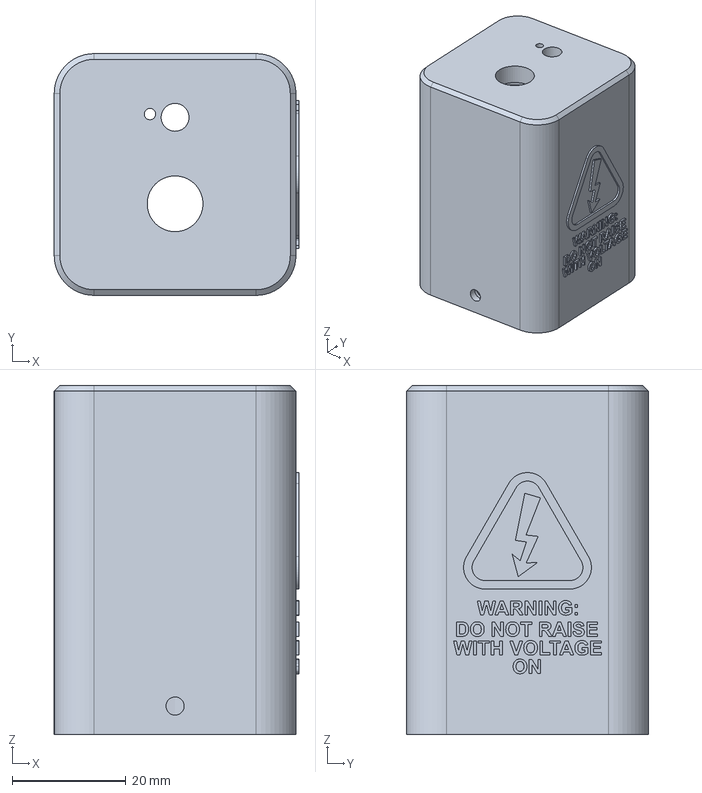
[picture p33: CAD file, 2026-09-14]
FreeCAD/Cap.FCStd
43.0 x 42.5 x 61.4 mm
ShapeString
ShapeString001
ShapeString002
ShapeString003

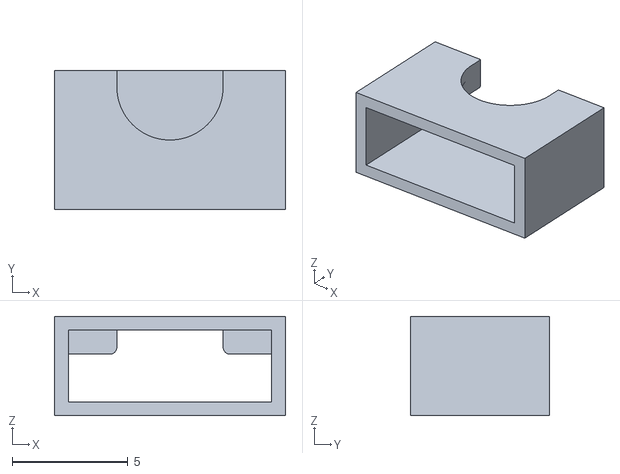
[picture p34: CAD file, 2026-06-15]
STL/Opensource_Strip-Holder-clip.stl
10.0 x 6.00 x 4.30

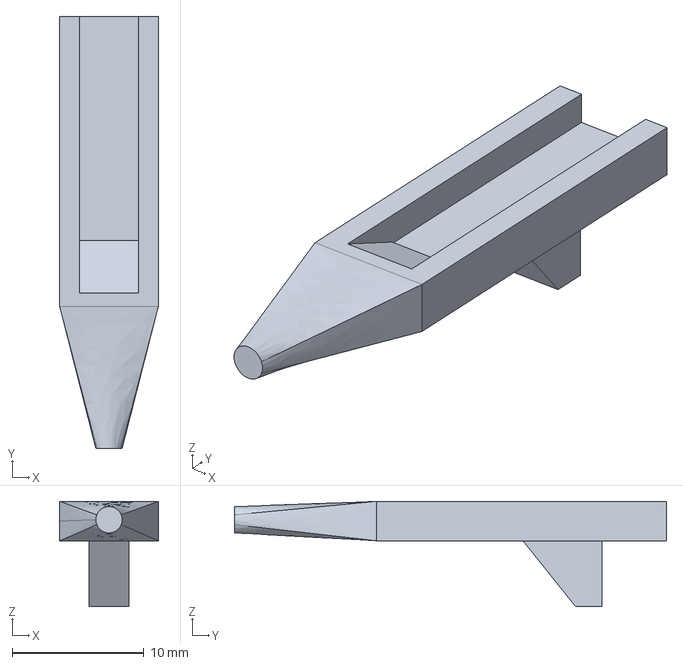
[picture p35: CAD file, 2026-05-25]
FreeCAD/Calibration_strip_commercial.FCStd
7.50 x 32.8 x 8.00 mm

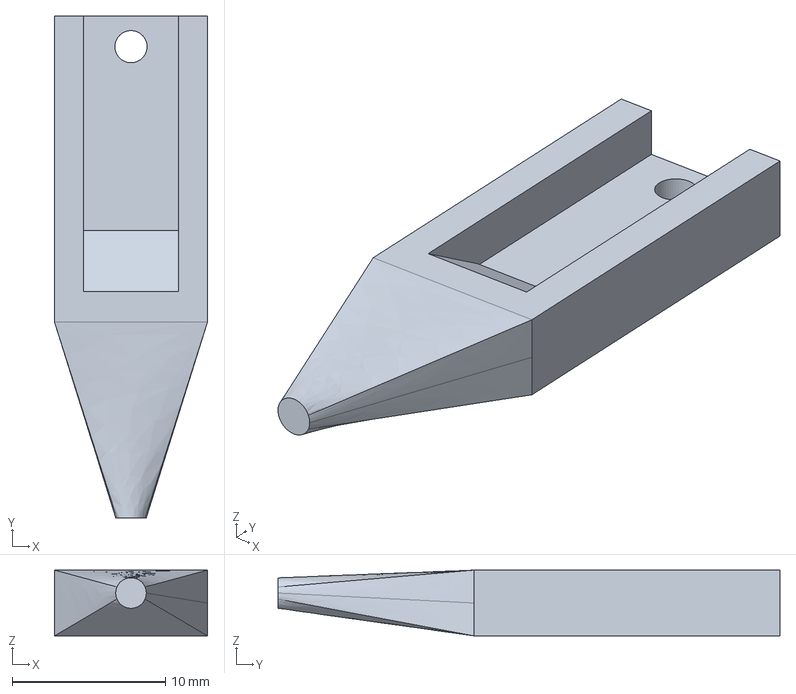
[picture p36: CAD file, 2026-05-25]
FreeCAD/Calibration_strip_open.FCStd
10.0 x 32.8 x 4.30 mm

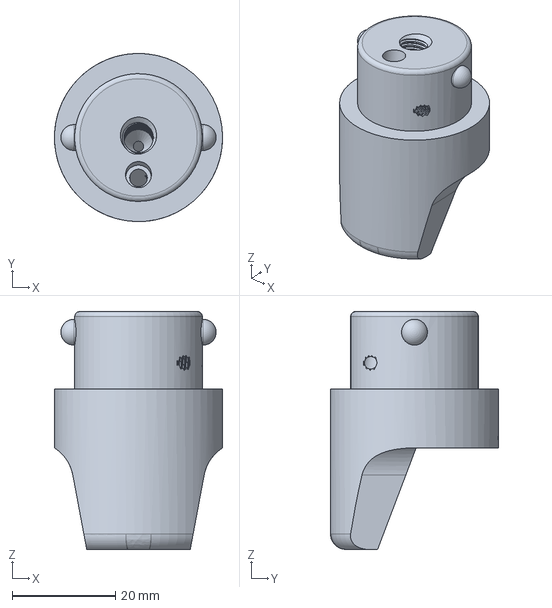
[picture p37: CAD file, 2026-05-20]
FreeCAD/Commercial_strip-mount.FCStd
32.5 x 32.5 x 46.0 mm

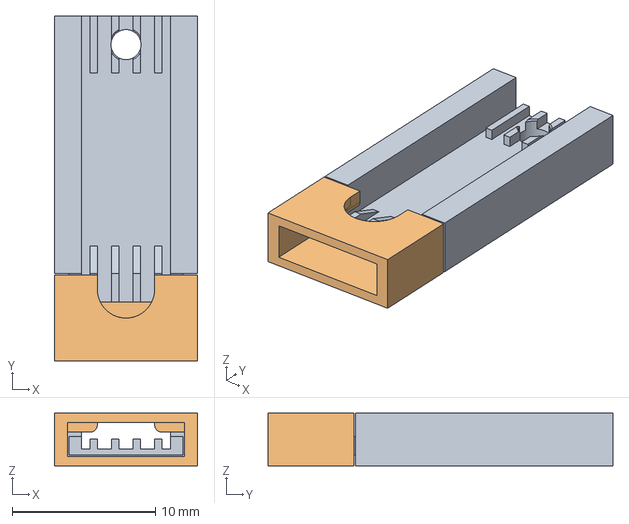
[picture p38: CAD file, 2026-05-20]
FreeCAD/Opensource_strip-holder.FCStd
10.0 x 24.1 x 3.70 mm
Strip_Holder
Strip_Holder_Clip

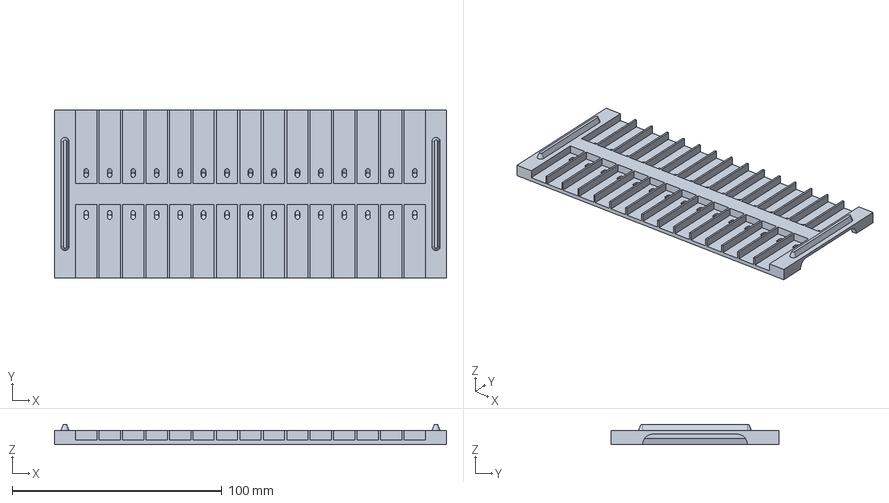
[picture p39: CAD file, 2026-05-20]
FreeCAD/Opensource_strip-tray.FCStd
187.0 x 80.0 x 9.60 mm

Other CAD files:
STL/Cap.stl
STL/Opensource_Strip-Holder.stl

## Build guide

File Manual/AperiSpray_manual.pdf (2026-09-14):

# Table of Contents

Table of Contents | 2
1.0 | Overview of Source | 3
1.1 Schematic | 3
1.2 Parts list | 4
2.0 Source construction | 5
2.1 Printing parts | 5
| 2.1.1 Filament | 5
| 2.1.2 Printer settings | 5
| 2.1.3 Slicer settings | 5
2.2 Source Disassembly | 8
2.3 Soldering Electronics | 13
2.4 Assembling the shaft assembly | 16
2.5 Assembling the High-Voltage Termination. | 21
2.6 Installing the strip mount | 23
2.7 Installing assembly in the ESI housing | 27
3.0 Opensource Strip Cartridge Construction | 29
3.1 Cutting Paper Strips | 29
3.2 Printing Strip Holders and Strip Holder Clips | 29
3.3 Assembling Strip Cartridges | 30
4.0 Operating Instructions | 32
4.1 Positioning Calibration Procedure | 32
4.2 Spray Solvent Delivery Set Up | 33
4.3 Method Development | 33
4.4 Sample Preparation | 34
4.5 Loading and Analyzing a Strip Cartridge | 34
4.6 Troubleshooting | 36
4.7 Unloading Used Strip Cartridges | 36

# 1.0 Overview of Source

The AperiSpray is a low-cost, simple to use assembly that converts existing Thermo Scientific IonMax and OptaMax NG heated electrospray ionization (H-ESI) housings into paper spray ion sources, making use of 3D-printed parts and off-the-shelf hardware. AperiSpray features instrument-controlled high-voltage and spray solvent delivery and can use either in-house-built or commercially available paper spray strip cartridges. Many laboratories that perform routine LC-MS analyses already have surplus H-ESI sources available for conversion, and those that don’t can purchase inexpensive used or defective housings from third-party sellers, making AperiSpray a low-investment option for those wanting to experiment with PS-MS. Additionally, unlike the commercial PS-MS platform, AperiSpray is compatible with almost any Thermo Scientific mass spectrometer with an atmospheric pressure interface, allowing it to be coupled to high-resolution Orbitrap and time-of-flight instruments.

# 1.1 Schematic

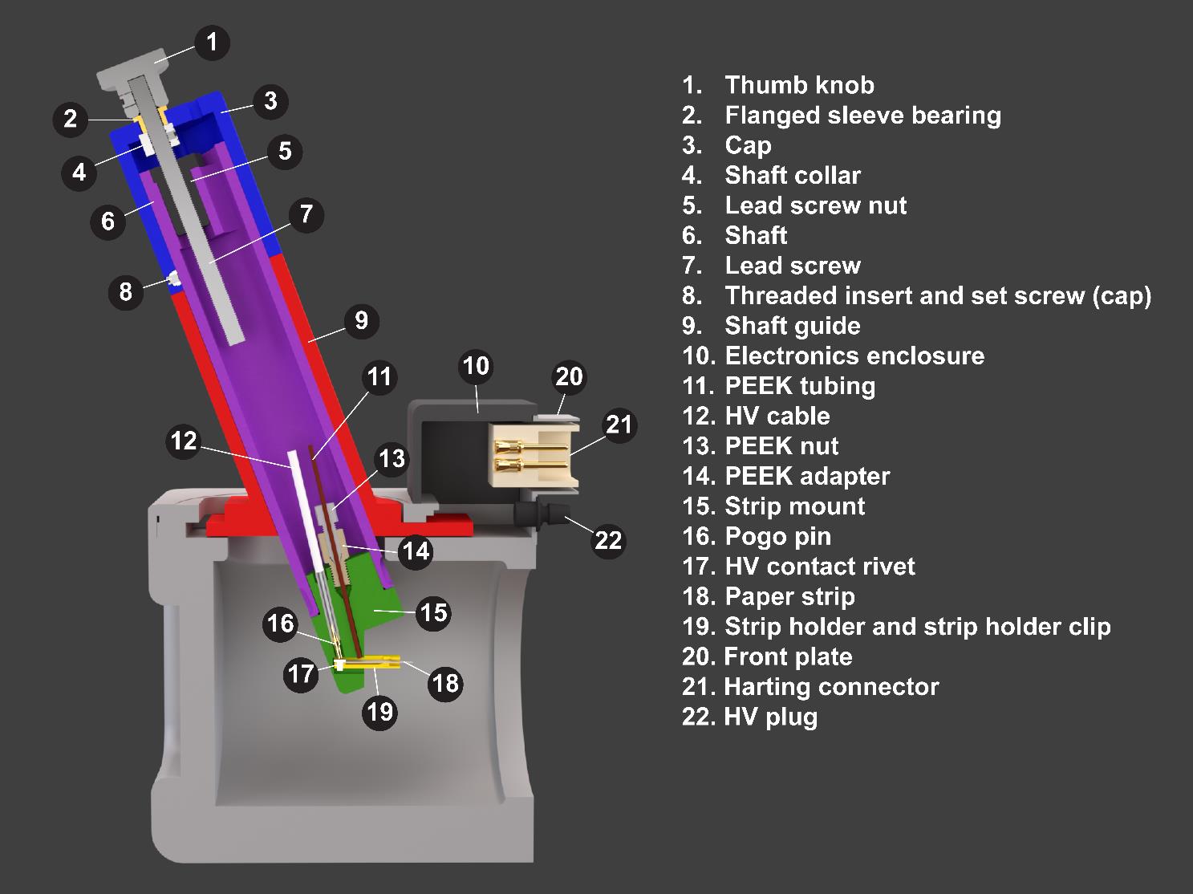
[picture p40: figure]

# 1.2 Parts list

Identifier | Qty | Source | Part No. | Cost /ea (CAD) | Material
Shaft guide | 1 | 3D-printed | N/A | 2.43 | PLA-CF
Shaft | 1 | 3D-printed | N/A | 2.46 | PLA-CF
Cap | 1 | 3D-printed | N/A | 1.46 | PLA-CF
Electrical enclosure | 1 | 3D-printed | N/A | 1.60 | PLA-CF
HV female connector | 1 | 3D-printed | N/A | 0.16 | PLA-CF
Strip mount | 1 | 3D-printed | N/A | 0.72 | PA6-GF
Strip holder + clip | N/A* | 3D-printed | N/A | 0.06 | PA6-GF
Strip tray | 1 | 3D-printed | N/A | 0.73 | PLA
Harting connector | 1 | Digikey.ca | 1195-1808-ND | 29.82 | PC
2.15 kΩ resistor | 1 | Digikey.ca | 56-SFR2500002151FR500CT-ND | 0.20 | Ceramic
22 MΩ resistor | 1 | Digikey.ca | BC4913CT-ND | 0.74 | Ceramic
20 AWG wire | 4 cm | mcmaster.com | 8054T184 | 0.02 | Copper
Heat shrink | 1 | homedepot.ca | 1000843481 | 25.41 | Polyolefin
HV cable | 70 cm | mcmaster.com | 8296K17 | 25.67 | Silicone
Crimp butt connector | 1 | grainger.ca | GGE4FRH9 | 0.13 | Vinyl
Pogo pin | 1 | Digikey.ca | 54-7949-0-15-20-09-14-11-0-ND | 4.76 | Brass alloy
Pen tube | 1 | grainger.ca | TOYGSM11-2 | 0.47 | PP
1/4"-PP tubing | 6 cm | mcmaster.com | 5392K12 | 0.20 | PP
Threaded insert | 1 | mcmaster.com | 94100A110 | 0.70 | SS
Set screw (cap) | 1 | mcmaster.com | 92605A098 | 0.15 | SS
Thumb knob | 1 | mcmaster.com | 2577K21 | 12.57 | SS
Flanged sleeve bearing | 1 | mcmaster.com | 7815K11 | 5.17 | Bronze
Lead screw | 1 | mcmaster.com | 6350K694 | 81.44 | SS
Shaft collar | 1 | mcmaster.com | 6462K12 | 7.17 | SS
Lead screw nut | 1 | mcmaster.com | 6350K683 | 31.63 | POM
Mounting screws | 2 | mcmaster.com | 92196A151 | 0.11 | SS
Set screw (strip-mount) | 1 | mcmaster.com | 92765A005 | 0.33 | Steel alloy
HV contact rivets | N/A* | aliexpress.com | 3 mm M2 GB109 | 0.03 | Aluminum
Chromatography paper | N/A* | www.fishersci.ca | 057146 | 0.02 | Cellulose
PEEK nut | 1 | coleparmer.ca | 0201343 | 11.32 | PEEK
PEEK nut adapter | 1 | coleparmer.ca | 0201420 | 40.81 | PEEK
*Denotes consumables

# 2.0 Source construction

# 2.1 Printing parts

## 2.1.1 Filament

For the cap, shaft, shaft guide, electronics enclosure, and strip tray, most standard FDM filament materials are acceptable. We prefer carbon-fiber PLA because it is dimensionally stable, easy to print and has a desirable surface texture. For the strip mount and strip holders, we recommend a material that is resistant to solvent to prevent interference and instrument contamination. In normal operation of the source, the strip mount should not come in direct contact with spray solvent, so PLA or ABS can be used if necessary, however in our experience, solvent overflow will occasionally occur while calibrating solvent deposition rate and volume, so a solvent-resistant material is highly recommended. Strip holders come in contact with solvent during normal operation. Some good options for strip holders (and strip mounts) include natural polyoxymethylene (POM), and natural PA6 Nylon. We recommend natural glass fiber reinforced PA6 nylon as it is both chemically resistant and easy to print on consumer grade printers, whereas POM suffers from poor bed adhesion and severe warping.

## 2.1.2 Printer settings

Printer settings are highly dependent on the filament material and printer. We recommend using your printer’s default print settings for the filament chosen and adjusting as necessary.

## 2.1.3 Slicer settings

Shaft guide:

Print the shaft guide in an upright position. Tree support is recommended for the overhang in the loading cutaway.

Shaft:

We recommend printing the shat upright to ensure the surface that mates with the lead screw nut is flat. You will need support under the mounting bracket on the inside of the shaft.

Cap:

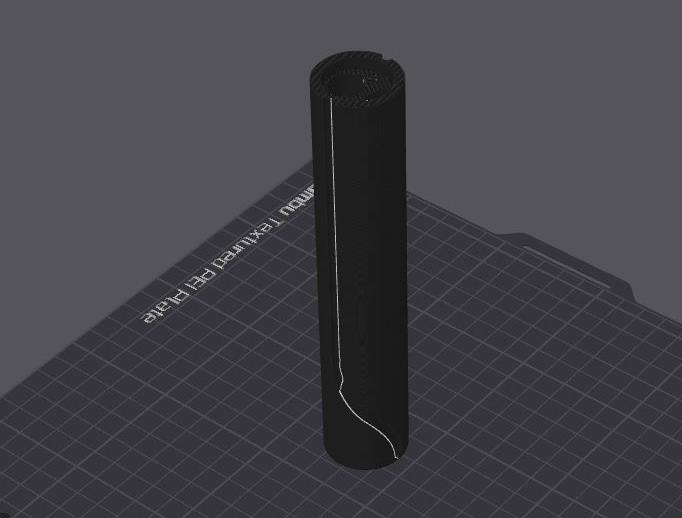
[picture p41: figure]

The cap should be printed upside down with the top face against the build plate. No support is necessary. We recommend using a contrasting filament for the warning text and HV symbol if multi-filament printing is available.

Electronics enclosure:

Print the electronics enclosure with the backside down on the build plate. Support is only needed for the bottom lips.

HV female connector:

Print with the threaded end up. No support is needed.

Strip mount (for open-source or commercial strip cartridges):

The strip mount is best printed upside down with support under the ridge, in the strip pocket, and in the threaded solvent hole.

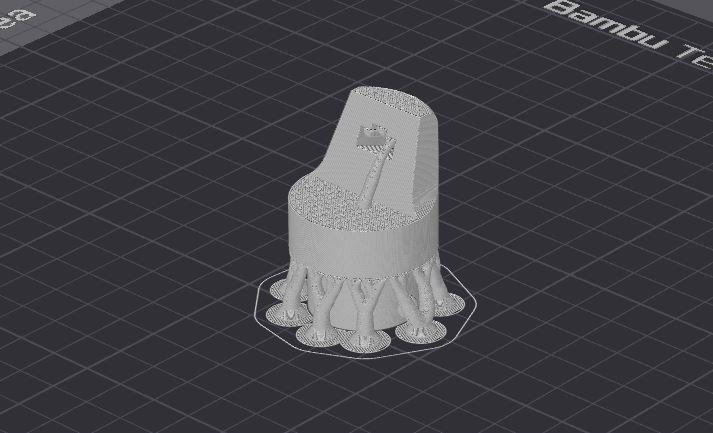
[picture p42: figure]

Calibration Strips:

Calibration strips are for calibrating the strip position relative to the inlet of the mass spectrometer. They are inserted into the strip pocket on the strip mount and extend to where the opening of the inlet should be relative to the strip mount. By default, the calibration strips extend 4 mm further from the strip mount than actual paper strips would to create a 4 mm gap between paper strips and the inlet when used to calibrate positioning. If a larger or smaller gap is desired, the FreeCAD file for the calibration strips can be modified by increasing or decreasing the “Inlet_gap” variable in the variable set. Print calibration strips out of whatever filament you have on hand. They are best printed in an upright position with the backside against the print bed. Support is only necessary on the calibration strip for the commercial strip mount.

# 2.2 Source Disassembly

Remove the 4 screws holding the front plate on the source and pull the front plate away from the housing.

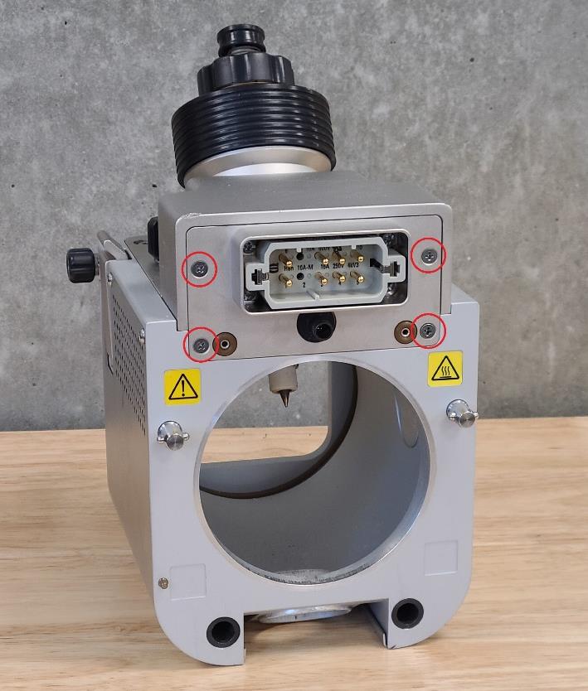
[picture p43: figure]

Remove the metal cover protecting the electronics connections.

Disconnect gas lines by pushing down on quick connect tab while pulling up on gas tubing. Remove the retainer knobs for the API spray insert and heater assembly and the 4 socket head screws that mount the spray insert and heater assembly to the housing.

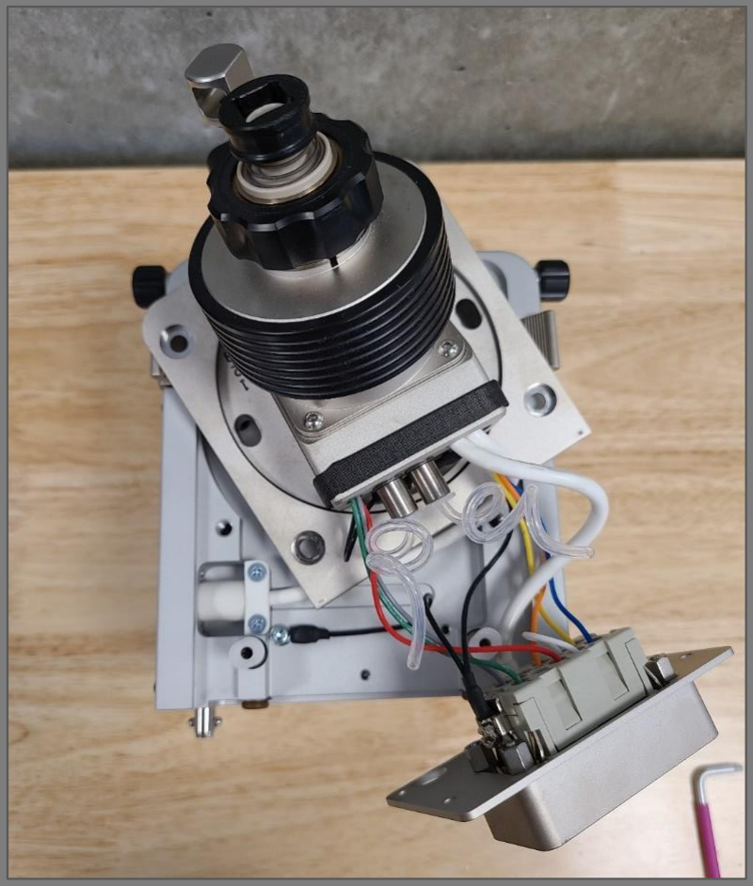
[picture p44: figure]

Remove the 3 socket head screws and the side panel on the right side of the housing.

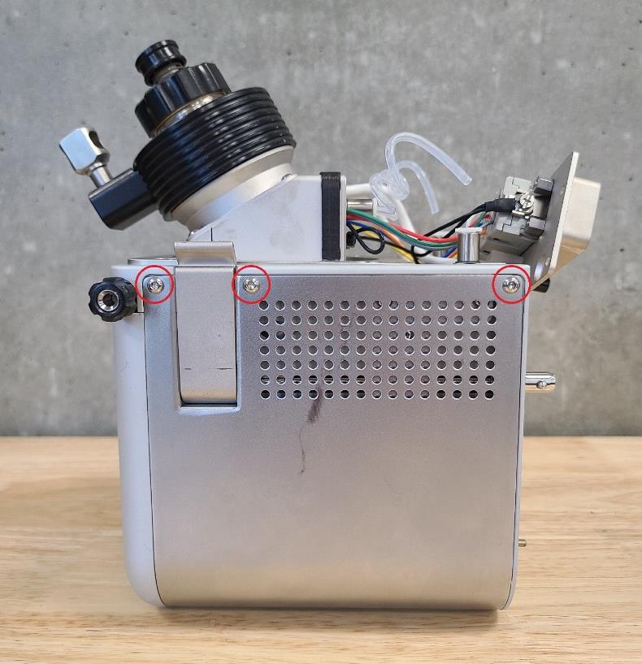
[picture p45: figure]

Remove the 4 socket head screws and metal plate covering the APCI corona discharge needle high-voltage connection.

Remove the 2 screws and the plastic mount housing the high-voltage corona discharge needle connector and adjacent grounding connection. The right-side panel can be replaced.

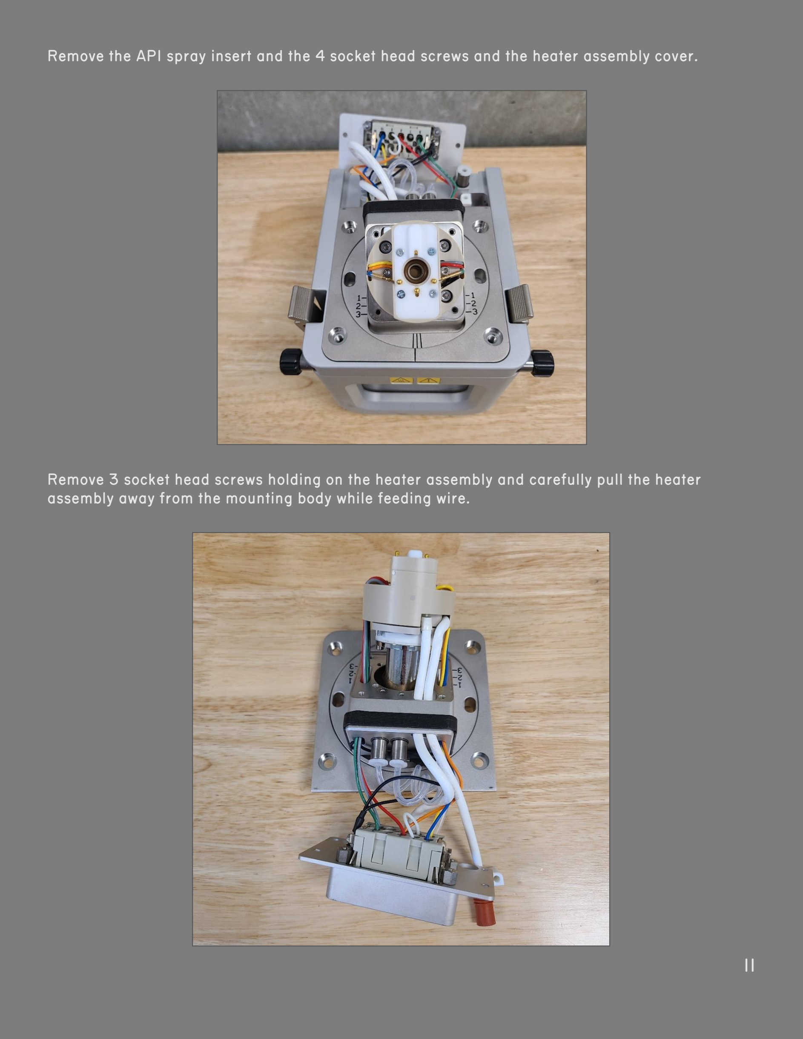
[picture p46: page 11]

Remove the API spray insert and the 4 socket head screws and the heater assembly cover.

Remove 3 socket head screws holding on the heater assembly and carefully pull the heater assembly away from the mounting body while feeding wire.

Carefully slide the positioning plates up and over the heater assembly and electrical connections to separate them from the electronic components

Loosen and remove the 4 nuts retaining the 10-pin Harting connector to the front plate and unscrew the transparent square nut connecting the HV wire to the HV plug on the front plate.

Separate the connector from the front plate.

# 2.3 Soldering Electronics

Add the nuts from the original Harting connector to the new one and mount the new connector to the front plate. Thread a 3/8-32 panel nut onto the HV plug to clamp it to the front plate and tighten it to prevent the HV plug from turning freely in the front plate.

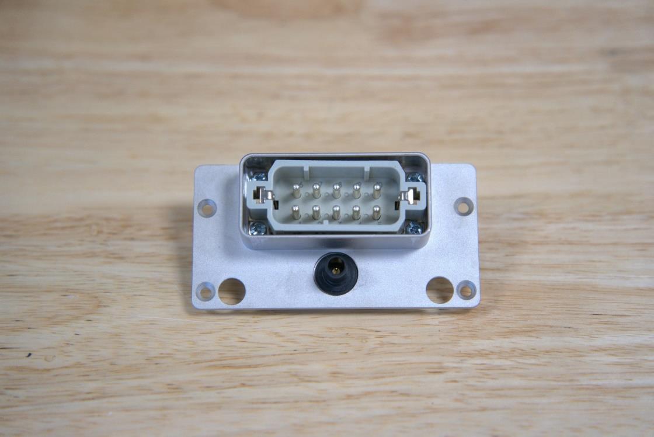
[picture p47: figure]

Cut a 10 cm section of HV wire and strip 1 cm from each end. Cut a second 60 cm section and strip 1 cm from one end. Solder the 22 MOhm resistor between the two sections of HV wire. Cut a 6 cm section of 1/4”- polypropylene tubing and slide it over the resistor.

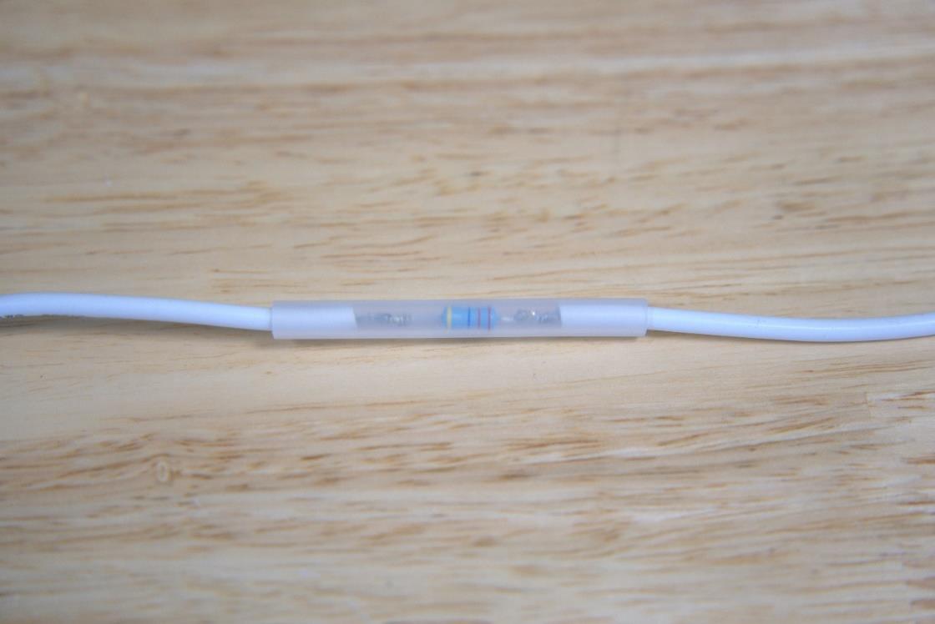
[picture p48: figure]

Add heat shrink over the tubing. Add a short section of heat shrink to each end of the previous heat shrink to prevent the tube from sliding. Feed the long end of the HV cable through the port in the top of the 3D-printed electronics enclosure and carefully fold the resistor in.

Cut the plastic insulation off one end of a butt splice crimp connector using wire cutters.

Slide the 3D-printed HV connector onto the short end of the HV wire with the threaded end facing out. Feed the short end of the HV wire into the uncut end of the crimp connector and crimp. Slide the cut end of the crimp connector over the gold-plated solder well on the inside end of the HV plug mounted to the front plate. It should slide on easily but make firm contact.

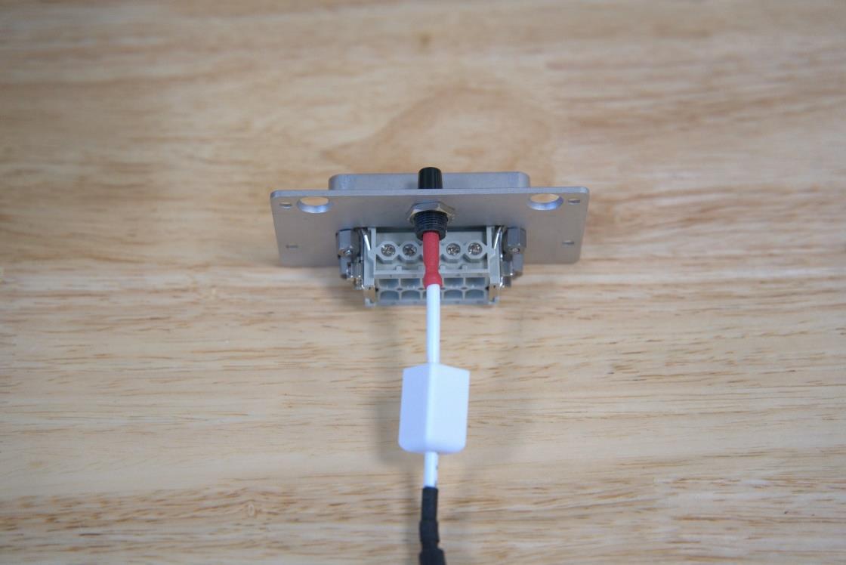
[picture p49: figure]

Heat shrink a 2.15 kOhm resistor, leaving the last 5 mm of each lead exposed. Strip 5 mm from each end of a 4 cm section of wire to make a jumper. Place the resistor between pins 6 and 10 in the Harting connector and place the wire jumper between pins 4 and 9. Tighten the set screws fix the connections.

Thread the 3D-printed HV female connector onto the inside end of the HV plug and tighten to secure the crimped HV line to the HV plug. Carefully fold the HV cable into the 3D-printed electronics enclosure and mount the front plate to the electronics enclosure using the 2 of the original flush head mounting screws.

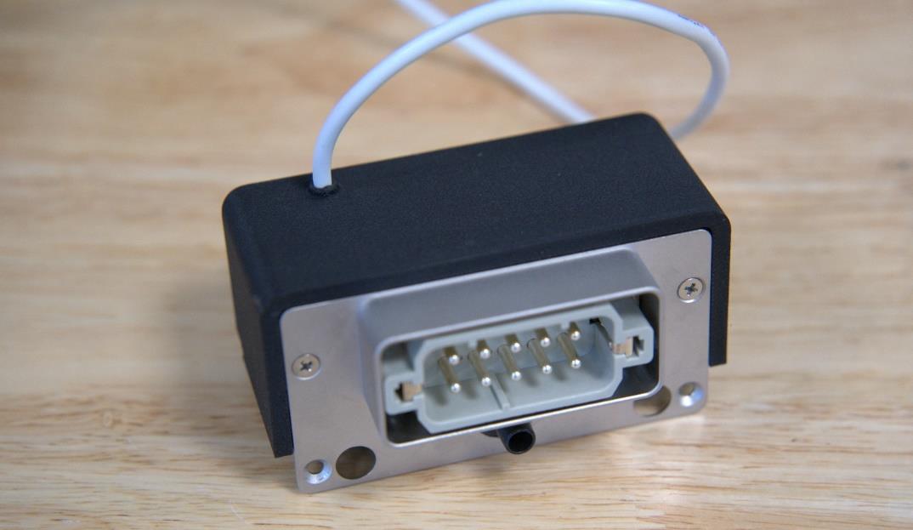
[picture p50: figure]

# 2.4 Assembling the shaft assembly

Cut the 1/4-40 lead screw to a length of approximately 9 cm using whatever cutting tool you have on hand. The threads on the cut end do not need to be preserved. Modify the lead screw nut so it fits into the shaft with the two mounting holes lining up with the corresponding threaded holes on the shaft. The nut is made of acetal/POM, so it is easily shaped with common tools (files, hacksaw, dremel, etc.)

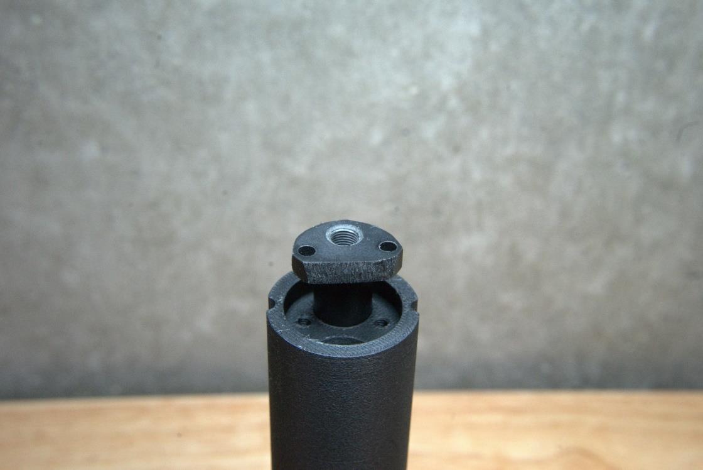
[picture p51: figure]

Thread the uncut end of the lead screw into the lead screw nut from the bottom until approximately 29 mm protrudes from the top of the nut. Mount the lead screw nut in the 3D-printed shaft using two 6-32 screws.

Slide the shaft up through bottom of shaft guide by lining up the grooves in the shaft with the guide pins on the inside of the guide shaft. All 3D printers print slightly differently, so tolerances may need to be adjusted in the original design files. Variable sets have been included in each design file to simplify adjustments of critical dimensions. If the shaft does not slide smoothly in the shaft guide, you may need to increase the bore diameter of the shaft guide by editing the “Bore_diameter” variable in the FreeCAD file for the shaft guide. If the shaft is too loose in the shaft guide, decrease the bore diameter. If the shaft slides smoothly in the shaft guide but cannot pass the guide pins, you may need to increase the pin-to-pin distance (“Pin_to_pin_distance” variable in the FreeCAD file for the shaft guide) or decrease the pin radius (“Pin_radius” variable). If the shaft has rotational play, you may have to decrease the pin-to-pin distance or increase the pin radius.

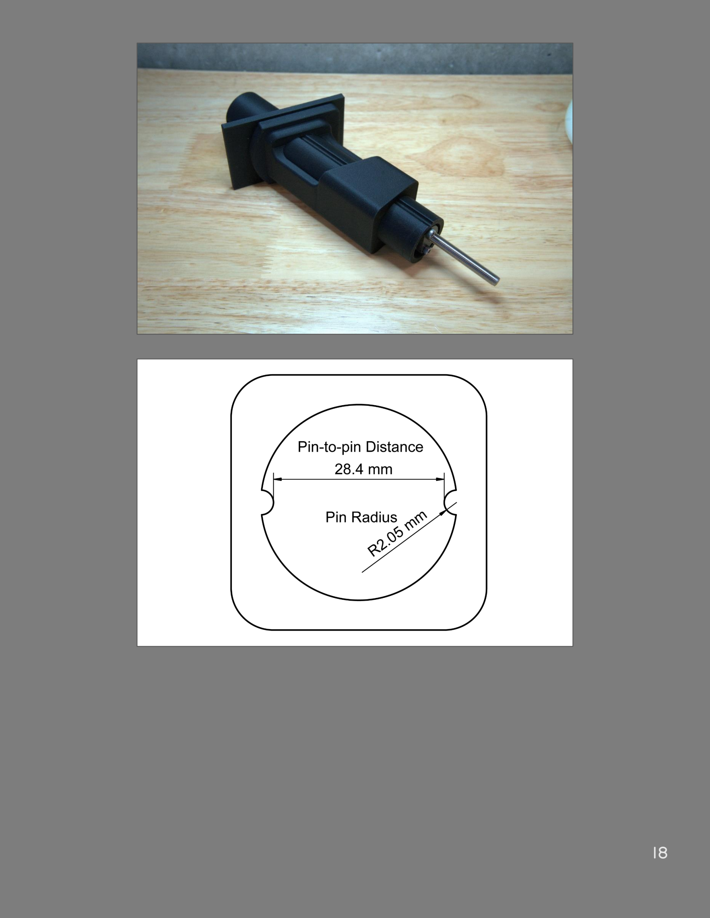
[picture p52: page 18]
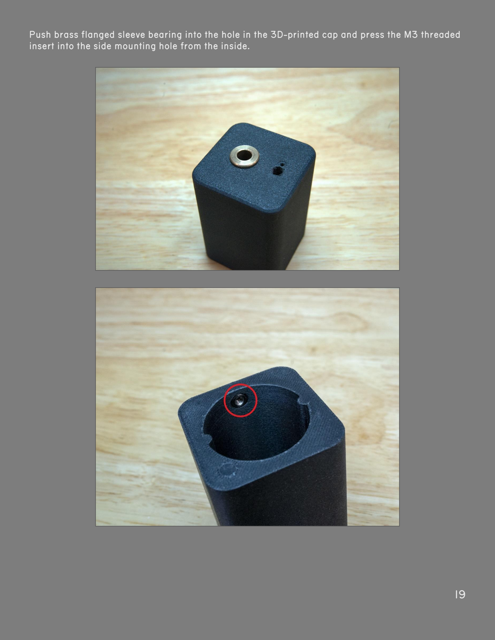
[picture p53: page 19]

Push brass flanged sleeve bearing into the hole in the 3D-printed cap and press the M3 threaded insert into the side mounting hole from the inside.

Slide shaft collar over the top end of the lead screw and tighten the set screw 13 mm below the top.

Guide lead screw up though the brass bushing in the cap. Slide the thumb knob onto the lead screw. While pushing the thumb knob against the shaft collar, tighten the set screw on the thumb knob to fix it to the lead screw. Turn the thumb knob clockwise while lining up the grooves on the shaft with the ridges on the inside of the cap until the cap slides over the shaft.

Thread M3 set screw into threaded insert on back side of cap, but don’t tighten it all the way. Feed the free end of the HV wire coming from the electrical enclosure through the hole in the top of the cap and down through the shaft. Do the same with one end of the PEEK line.
2.5 Assembling the High-Voltage Termination.

Disassemble a Bic Round Stic® pen and flush the polypropylene ink cartridge tube out with methanol to remove all the ink. Cut a 60 mm section of the pen tubing. Strip 70 mm of insulation off terminus of HV wire. Slide a 60 mm section of heat shrink onto the stripped portion of the wire and heat.

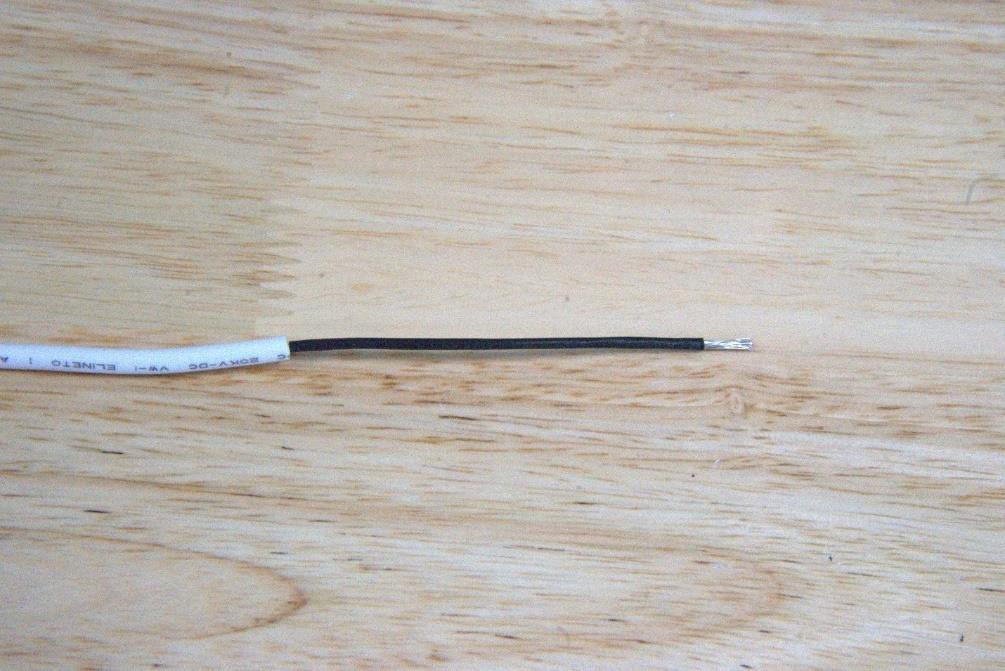
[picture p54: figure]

Slide the plastic pen tube over the heat-shrinked portion of the wire all the way to the terminus of the insulation and solder the HV pogo pin onto the terminus of the wire.

Slide the plastic tube down onto the splines of the pogo pin and heat shrink where the plastic tube meets the HV wire insulation.

# 2.6 Installing the strip mount

(procedure is the same whether using the commercial strip cartridges or strip cartridges produced in-house).

Feed PEEK tubing and the HV terminus through the holes on the top surface of the cap and down through the shaft.

Slide a 10-32 threaded (male) 1/16-inch nut onto the end of the PEEK line. Slide a 10-32 to 1/4-28 adapter onto peak line and begin to thread the 1/16-inch nut into the adapter. Position the bottom of adapter 32 mm from terminus of PEEK line and tighten connection to clamp the PEEK fittings in place on the PEEK tubing.

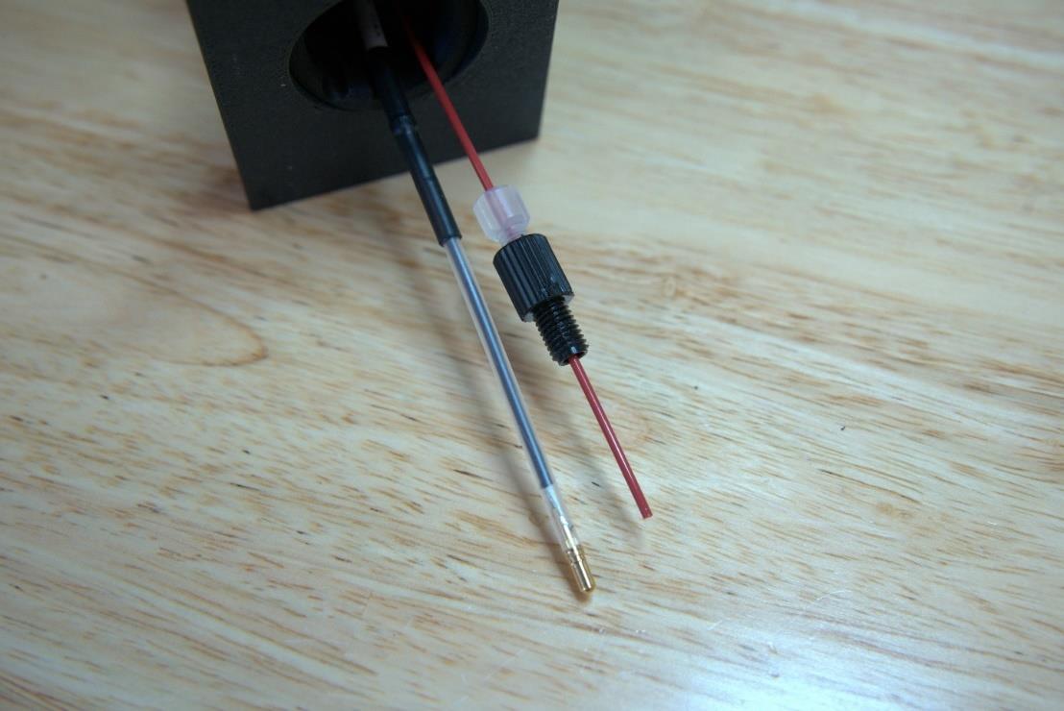
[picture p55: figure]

Feed the PEEK terminus into the threaded hole in the 3D-printed strip mount, and the HV terminus into the unthreaded hole. Thread in the 1/4-28 PEEK adapter while ensuring the PEEK tubing is rotating freely within the shaft assembly. Thread the 4-40 set screw into the threaded hole on the side of the strip mount but don’t fully tighten.

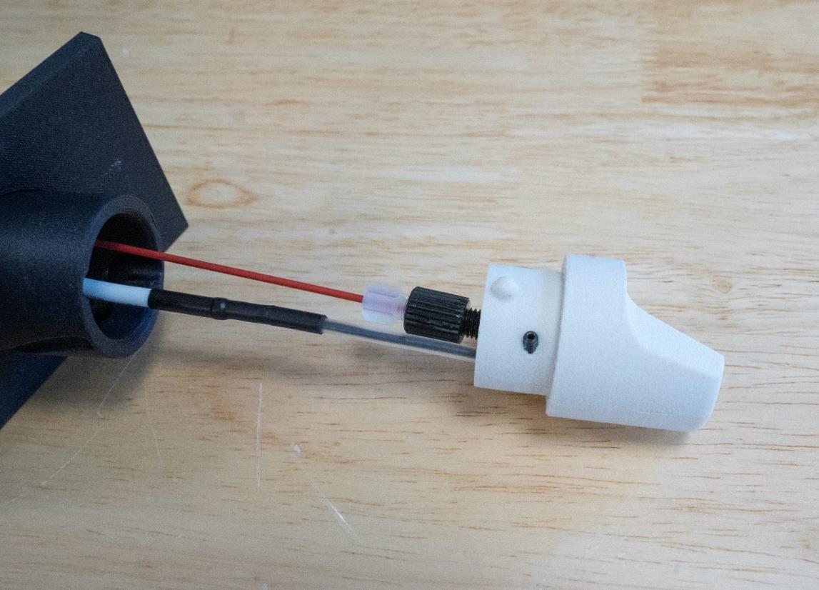
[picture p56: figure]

Insert a strip cartridge into the strip mount and ensure it is fully seated. If the strip cartridge does not slide in easily, you will need to increase the vertical tolerance by decreasing the “Strip_Height” variable in the FreeCAD file for the strip holder (if using opensource strip cartridges), or by increasing the “Strip_pocket_height” variable in the FreeCAD file for the strip mount (if using commercial strip cartridges). If the strip cartridge is loose in the strip mount, you will need to decrease tolerances. Slide the high voltage terminus into the strip mount until it contacts the rivet on the strip cartridge (look down along top of paper strip to ensure). Push it an additional mm to ensure good contact between pogo pin and rivet, but not so far that the pogo pin is fully depressed. Tighten set screw on the side of the strip mount to fix the height of the high voltage contact.

Turn the PEEK adapter nut clockwise until the PEEK terminus is roughly 1 mm above the surface of the paper strip (make sure the PEEK is turning freely within the shaft assembly so as not to introduce torsion in the PEEK tubing). The following image shows a strip mount with properly adjusted high voltage contact and solvent line.

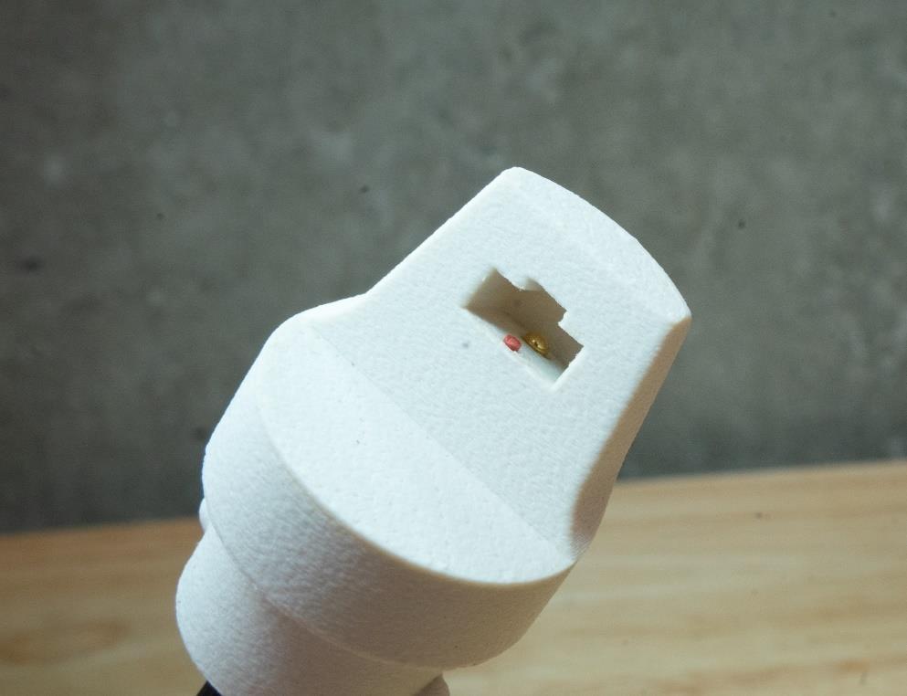
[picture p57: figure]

Line up locking lugs on insert with slots on the shaft, slide insert into shaft while twisting clockwise until insert clicks into place. Pull extra slack in high voltage line up through the cap.

# 2.7 Installing assembly in the ESI housing

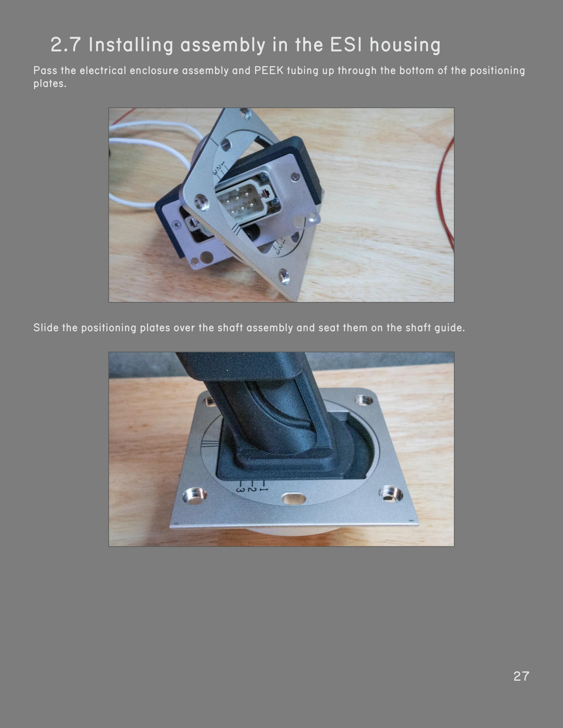
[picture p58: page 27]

Pass the electrical enclosure assembly and PEEK tubing up through the bottom of the positioning plates.

Slide the positioning plates over the shaft assembly and seat them on the shaft guide.

Mount the positioning plates and shaft assembly to the ESI housing and replace the 4 mounting screws. Replace the left thumbscrew only, to allow easier access to the loading port in the shaft guide when loading and unloading strip cartridges.

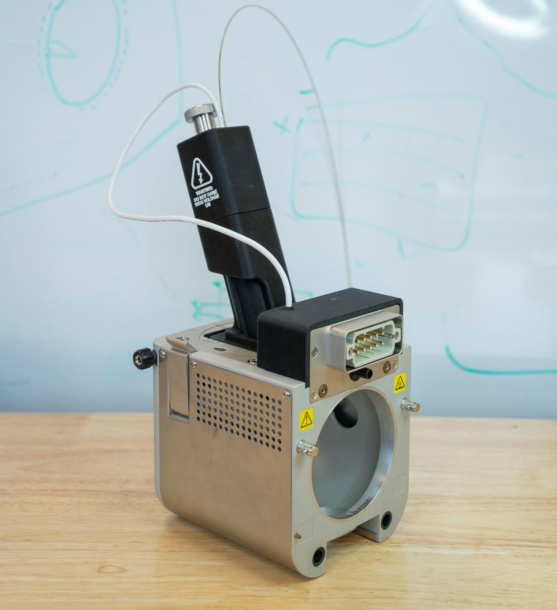
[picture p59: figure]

# 3.0 Opensource Strip Cartridge Construction

# 3.1 Cutting Paper Strips

If you choose to make your own paper strips, you will need to have a method of cutting the strips out of the chromatography paper. Paper strips can be cut by hand using a razor blade, by custom die cutters, or by a laser cutter. Whichever technique is chosen, it is crucial that the tip of the paper is cut to a fine point without any fraying otherwise you may experience unstable spray. If using a laser cutter, we recommend rinsing the strips in deionized water prior to use to remove pyrolysis products generated from the heat of the laser. We have included an .svg file for laser cutting. Laser settings must be optimized for your specific laser cutter.

# 3.2 Printing Strip Holders and Strip Holder Clips

The FreeCAD file for the strip holder contains the strip holder clip as well. Print the strip holders and the strip holder clips standing vertically with the back surfaces on the build plate. Support should not be necessary, as the overhangs are minimal.

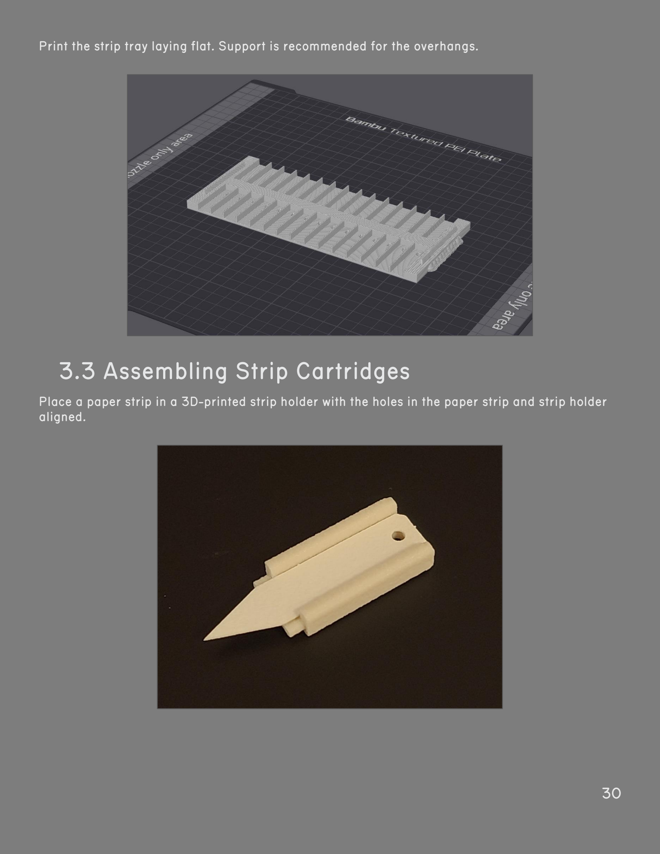
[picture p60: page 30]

Print the strip tray laying flat. Support is recommended for the overhangs.

# 3.3 Assembling Strip Cartridges

Place a paper strip in a 3D-printed strip holder with the holes in the paper strip and strip holder aligned.

Insert an M2 rivet into the hole in the strip holder and press down until the paper strip is clamped flat against the strip holder.

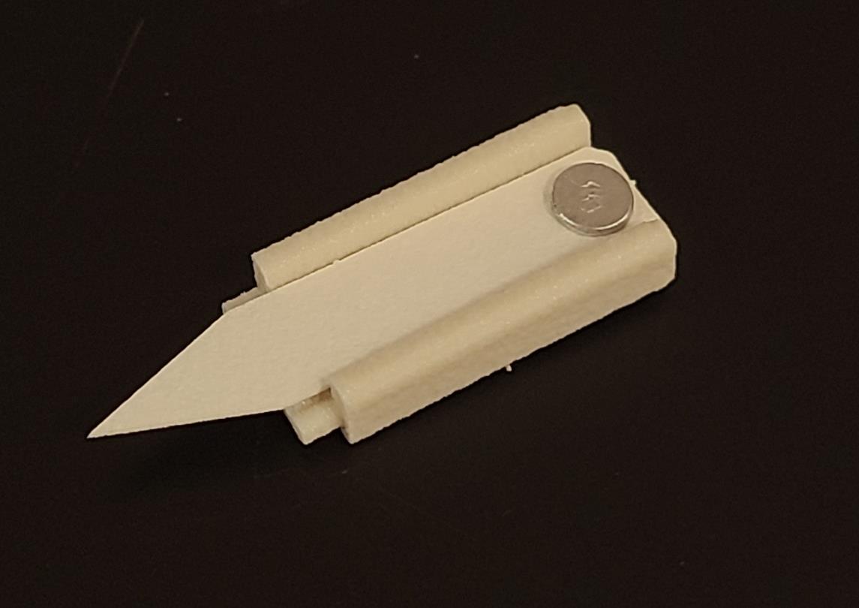
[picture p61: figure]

Slide a 3D-printed strip holder clip over the end of the paper strip and onto the strip holder until it clicks. Be careful not to damage the tip of the paper. The paper should be laying flat in the strip holder. You may need to modify tolerances in the FreeCAD file for the strip holder clip and/or strip holder to ensure a snug fit.

Put each assembled strip cartridge into a 3D-printed strip tray for storage until use.

# 4.0 Operating Instructions

The following instructions assume familiarity with instrument software and general instrument use. Refer to your instrument user manual for more specific instructions.

# 4.1 Positioning Calibration Procedure

- Turn off the heat to the ion transfer tube / inlet and allow it to fully cool.
- Loosen the 3 socket head screws and remove the left side panel from the source. Using your fingers, push the view port plug out of the source housing from the inside.

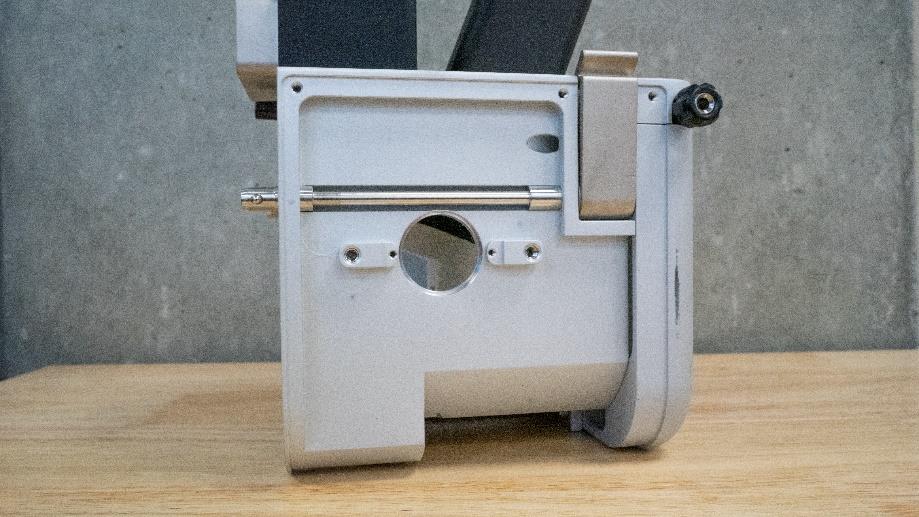
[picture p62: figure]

- With source removed from the instrument and the shaft at the bottom of its travel, insert a distance calibration strip and slide the shaft assembly to the back of its travel.
- Mount the source to the instrument.
- While looking through the side view port, slide the shaft assembly forward until the calibration strip is close to the inlet. Adjust the vertical positioning of the calibration strip by turning the thumb knob on the shaft assembly until the center of the calibration strip is aligned with the inlet. When the desired height is reached, tighten the set screw on the backside of the cap.

- To calibrate the gap between the inlet and paper strips, slide the shaft assembly forward until the calibration strip touches the inlet. It is crucial that the inlet is cool for this step, or the calibration strip may melt onto the ion transfer tube and contaminate the instrument. Tighten the black retainer knob on the source housing to clamp the shaft assembly in position.
- Remove the source from the instrument and remove the calibration strip from the strip mount. The viewport plug and side panel can be replaced.

# 4.2 Spray Solvent Delivery Set Up

The free end of the PEEK tubing can be terminated with a Luer-Lok adapter and connected to a 10 mL glass syringe filled with the desired spray solvent. We recommend priming the solvent delivery line before mounting the first strip cartridge to be run to remove air from the solvent line.

Using a syringe pump connected to the instrument allows solvent delivery to be programmed into the instrument method along with voltage and scan parameters.

# 4.3 Method Development

The source should be recognized by the instrument as an ESI source. Develop the instrument method as a direct infusion ESI method. If the source is not recognized, check the resistance across pins 6 and 10 on the Harting connector. You may need to replace the resistor if resistance is greater or less than 2.15 kΩ.

Spray solvent should be selected based on the matrix that your sample is in and the analytes of interest. Refer to the literature for examples of spray solvent composition for different applications.

Program solvent delivery to start at the beginning of the method before voltage turns on to give the analytes time to dissolve into the solvent and the solvent time to wick to the tip of the paper. It takes approximately 120 µL of spray solvent to wet a paper strip, so the solvent flow rate will determine the amount of time needed to pre-wet the paper. Exact solvent flow rates and deposition volumes can be altered to optimize sensitivity and achieve stable spray for the desired method duration. The amount of solvent on the paper can affect the spray mode, which in turn affects ionization and transmission efficiency. A good starting point is a flow rate of 300 µL/min for 0.4 minutes

Program the voltage to come on once the paper strip is wet. We recommend optimizing spray voltage for the spray solvent, sample matrix, and analytes you are interested in, but 3600 – 4000 V are typical for paper spray methods in positive mode. Negative-mode paper spray requires lower spray voltages to prevent corona discharge and charring of the paper. The duration of high voltage depends on the desired length of the method. Paper spray methods can range from a few seconds to several minutes.

Program data acquisition to continue for several seconds after the voltage turns off so the signal returns to baseline at the end of the method. This will simplify peak integration during data processing.

# 4.4 Sample Preparation

A diverse variety of sample types are amenable to paper spray mass spectrometry including but not limited to biofluids, water samples, health supplements, pharmaceuticals, forensic residues, and tissue homogenates. In most cases, little to no sample preparation is required and samples can be directly deposited on the paper strips without prior filtration or extraction steps. A sample deposition volume of 10 µL is standard, but lower volumes are sometimes used for complex sample matrices.

Samples should be allowed to dry on the paper, either at ambient conditions or with the help of a drying oven or desiccator prior to analysis.

# 4.5 Loading and Analyzing a Strip Cartridge

To load a strip cartridge, raise the shaft to its upward position by pulling upwards on the cap. The shaft and cap rotate 90° clockwise in the shaft guide to allow strip cartridges to be loaded from the cutout in the right side of the shaft guide.

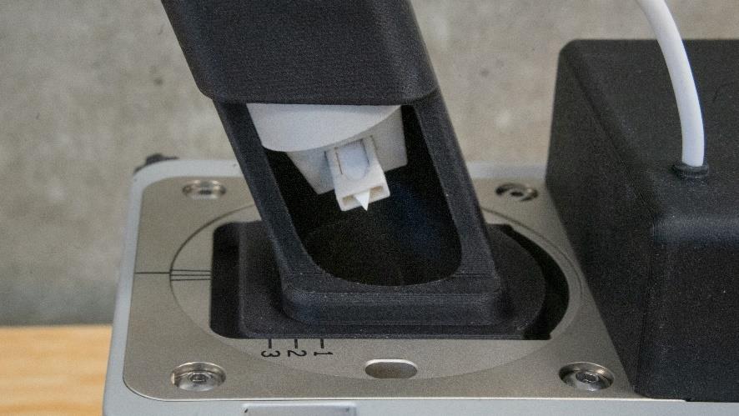
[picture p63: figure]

Ensure the strip cartridge is properly seated in the strip mount and slide the shaft to the bottom of its travel. The bottom of the cap should be flush with the top of the shaft guide.

The strip cartridge is now loaded, and you can start the instrument method. You should get a sharp increase in signal when the voltage turns on and a sharp decrease in signal when the voltage turns off.

# 4.6 Troubleshooting

A common issue is solvent overflow caused by excess solvent deposition. This will be noticeable when changing strip cartridges as the sides and bottom of strip holders will be wet with solvent. When this occurs, reduce either the solvent flow rate or the duration of deposition.

If the signal doesn’t come on, there is either a problem with the instrument method, the electrical contact, the solvent delivery, or the positioning of the paper strip relative to the inlet. Try the following steps in order:

With the voltage turned off, raise the shaft to the upward position and visually inspect the paper strip for solvent. It should be saturated with solvent but not overflowing or forming a drop at the tip. If there is no solvent, prime your syringe pump to remove air and check your instrument method to confirm it is programmed correctly to deliver solvent. You may need to increase the solvent delivery rate / duration.

If solvent is flowing but the paper is not getting wet, solvent may be wicking up the outside of the PEEK tubing into the strip mount. To resolve this, increase the inner diameter of the PEEK tubing.

If the paper looks saturated with solvent and there is still no signal, try moving the shaft assembly forward to decrease the inlet gap.

If there is still no signal, remove the source from the instrument and use a multimeter to confirm continuity between the pogo pin and the HV plug. There should be approximately 22 MΩ of resistance. If there is no continuity, remove the electronics enclosure and determine where the connection is broken.

If the HV line has appropriate resistance, check your instrument method to confirm the voltage and scan parameters are correctly programmed.

If the signal onset is delayed or choppy, try increasing the voltage onset delay or move the shaft assembly forward or back.

# 4.7 Unloading Used Strip Cartridges

To unload a strip cartridge after data has been acquired and the high voltage is turned off, raise the shaft to the upward position and use gloved fingers or forceps to extract the used strip cartridge. If there is solvent in the strip well on the strip mount, lower the solvent deposition volume for subsequent runs to prevent carryover. The high-voltage contact rivets can be washed and re-used, but the rest of the strip cartridge should be properly disposed of.

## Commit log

2026-05-20 Uploaded media and design files
    [Cap.FCStd, Cap.stl, Commercial_strip-mount.FCStd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]
2026-05-25 updated readme, uploaded calibration strips
    [Calibration_strip_commercial.FCStd, Calibration_strip_open.FCStd]
2026-06-08 modified shaft guide tolerances
2026-06-15 Updated STLs
    [Opensource_Strip-Holder-clip.stl, Opensource_Strip-Holder.stl]
2026-07-08 Updated open-source strip design
    Switched to rivets
2026-07-14 Updated schematic
2026-09-14 Safety improvements
    Added raised warning label to cap, and updated documentation.
    [Cap.FCStd]
